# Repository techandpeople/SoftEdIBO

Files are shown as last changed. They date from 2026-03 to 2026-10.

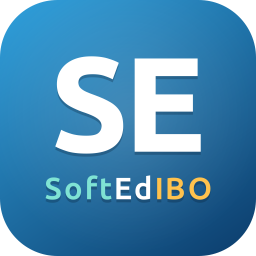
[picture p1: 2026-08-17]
softedibo.png

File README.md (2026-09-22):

# SoftEdIBO

Soft-based robot platform for inclusive, embodied interaction.
Developed at [LASIGE](https://www.lasige.pt/), Faculdade de Ciencias, Universidade de Lisboa.

SoftEdIBO controls soft robots equipped with inflatable air chambers.
Participants interact by touching the robots, which respond through inflation and deflation.
The system supports multiple robot types (Turtle, Tree, Thymio) and activity modes.

> **Running a study?** See [SETUP.md](SETUP.md) for skin/sensor setup, magnet
> polarity, touch calibration, and the gesture-training workflow.

---

## Hardware requirements

| Component | Quantity | Notes |
|---|---|---|
| Seeed XIAO ESP32-S3 (gateway) | 1 | Connected to PC via USB; also runs a WiFi SoftAP (WiFi-OTA) + a UART link to a companion XIAO ESP32-C6 for dongle-free Thymio control |
| Seeed XIAO ESP32-C6 (Thymio RCP) | 0-1 | Optional - impersonates the Thymio RF dongle over 802.15.4 (drive wheels/LEDs/sound, no dongle). See [docs/THYMIO_WIRELESS_CONTROL.md](docs/THYMIO_WIRELESS_CONTROL.md) |
| ESP32-WROOM-32 (`node_direct`) | 1 per direct board | 3 chambers, direct ADC sensors, onboard pumps |
| ESP32-WROOM-32 (`node_multiplexed`) | 1 per multiplexed board | Up to 12 chambers (runtime configurable) |
| DRV3297 motor driver | 1 (`node_direct`) / up to 3 (`node_multiplexed`) | Drives pumps with PWM |
| Air pump | 2 (`node_direct`) / up to 6 (`node_multiplexed`) | Inflate/deflate supply - pumps push directly into the chambers |
| XGZP6847A pressure sensor | 1 per chamber | Analog output (0-3.3 V) |
| Solenoid valves | 2 per chamber | Inflate + deflate via ULN2803A |

Flash the [gateway firmware](firmware/gateway/) to the USB-connected board - one
build, a **Seeed XIAO ESP32-S3** (ESP-IDF), which does everything: ESP-NOW chamber
control + a WiFi SoftAP (for WiFi-OTA) + a UART link to a companion C6 for Thymios.
For each node, choose the matching firmware target:

| Firmware | Path | When to use |
|---|---|---|
| `node_actuator` env `direct` / `direct_debug` | [firmware/node_actuator/](firmware/node_actuator/) | Direct board (fixed 3 chambers) |
| `node_actuator` env `multiplexed` / `multiplexed_debug` | [firmware/node_actuator/](firmware/node_actuator/) | Multiplexed board (default 12 chambers, runtime configurable) |
| `node_magnet_sensor` | [firmware/node_magnet_sensor/](firmware/node_magnet_sensor/) | 4x MLX90393 magnetic touch board (`node_magnet_sensor` protocol) |

---

## Architecture

```
PC --USB--> Gateway (XIAO ESP32-S3) --ESP-NOW--> node_direct      (3 chambers, direct GPIO valves + own pumps)
                                    |        +-> node_multiplexed (up to 12 chambers)
                                    +--UART--> C6 --802.15.4--> Thymio  (dongle-free wheels/LEDs/sound; optional)
```

**Software layers:**

```
SessionPanel
  +-- Activity (declarative behaviours run by ScriptedActivity)
        +-- Robot (Turtle / Tree / Thymio / Simulated)
              +-- Node(s)  (ESP32, identified by MAC + node_type + max_slots)
              +-- Skin(s)  (logical grouping of 1-3 chambers from one node of this robot)
                    +-- AirChamber  (local index 0-2, pressure 0-100 %)
```

- **Node** is a physical ESP32. Its `node_type` (`node_direct` or `node_multiplexed`) determines which firmware to flash.
- **Skin** groups 1-3 chambers, all on the same node (a skin never spans MACs). Activities address chambers by local skin index (0, 1, 2) - no knowledge of node topology required.
- **Pressure** is expressed as **0-100 %** of the maximum pressure configured on each node.
- **Per-chamber max pressure** is set in `settings.yaml` and enforced both in the app and on the ESP32 (hardware safety - survives app crashes).
- **Pressure sensing** uses the XGZP6847A datasheet transfer function (see [pressure.h](firmware/common/pressure.h)).

**Touch sensing (optional).** A skin may reference a `node_magnet_sensor` (4-sensor magnet sensor/touch board) via its `touch:` block - see [firmware/PROTOCOL.md](firmware/PROTOCOL.md). The activity-time view (`SkinGridView`) overlays a pulsing yellow outline on the active sensor cells so the operator sees where each touch lands relative to the chamber regions.

**Skin geometry by type.** Each skin sets a `skin_type` (e.g. `turtle_square`, `tree_round`, `thymio`) whose **shape and sensor coordinates** are hardcoded in [`src/hardware/skin_geometry.py`](src/hardware/skin_geometry.py). The skin dialog offers only the current robot's types and draws the real outline/aspect (square, rectangle, round, triangle, Thymio "D") - editor and activity view share the masks in [`src/gui/skin_shapes.py`](src/gui/skin_shapes.py). The legacy paint-grid editor still applies to skins without a `skin_type`.

**Sensor stream recording + touch-gesture ML.** A session can record every sensor message to `data/recordings/<id>.jsonl` (toggle in the setup dialog - no video). Those recordings, plus gestures tagged live in the observer panel, feed a **per-`skin_type`, coordinate-free** touch-gesture classifier (tap / press / compressions - `src/ml/gesture_taxonomy.py`). `scikit-learn` is the optional `ml` extra; the classifier is inert without a trained model. See [docs/TOUCH_ML.md](docs/TOUCH_ML.md).

**Activities are declarative behaviours.** No activities are hard-coded: every activity is a behaviour spec authored in the block editor (**Tools -> Activity Editor...**), stored in the DB (or imported from JSON examples in `config/examples/behaviours/`) and interpreted at session time by `ScriptedActivity`. See [docs/ACTIVITIES.md](docs/ACTIVITIES.md).

---

## Installation

### Linux (x86-64)

```bash
curl -fsSL https://raw.githubusercontent.com/techandpeople/SoftEdIBO/master/install.sh | bash
```

This will download the latest release, install it to `~/.local/opt/SoftEdIBO/`, create a `softedibo` command in `~/.local/bin/`, and add a desktop entry to the application menu.

**Nightly build** (latest commit on `master`):

```bash
curl -fsSL https://raw.githubusercontent.com/techandpeople/SoftEdIBO/master/install.sh | bash -s -- --nightly
```

**Uninstall:**

```bash
softedibo --uninstall
```

> **First time with USB?** After installing, run:
> ```bash
> sudo usermod -aG dialout $USER
> ```
> Then log out and back in. The installer does this automatically if needed.

---

### Windows (x64)

1. Download **`SoftEdIBO-windows-x64.zip`** from the [latest release](https://github.com/techandpeople/SoftEdIBO/releases/latest)
2. Extract and run **`SoftEdIBO.exe`**

> **USB driver:** install the [CH340](https://www.wch-ic.com/downloads/CH341SER_EXE.html) or [CP210x](https://www.silabs.com/developers/usb-to-uart-bridge-vcp-drivers) driver if your device is not detected.

---

## Usage

On first launch, a setup wizard guides you through flashing the firmware to the ESP32 nodes.

### Configuration (`settings.yaml`)

The app reads and writes the **user copy** of the settings file:
`~/.local/share/SoftEdIBO/config/settings.yaml` on Linux,
`%APPDATA%\SoftEdIBO\config\settings.yaml` on Windows. On first run it is copied
from the bundled default, the repo's [config/settings.yaml](config/settings.yaml);
later edits to the repo file do not reach an existing user copy.

Robots are configured per type (`turtles:` / `trees:` / `thymios:`), each with its own `nodes:` (ESP32s by MAC) and `skins:` on top. A skin lists its chambers - each a `{mac, slot}` pair on a single node - with optional per-chamber `max_pressure` / `min_pressure` safety limits in kPa. It is all editable from the GUI (Robots panel); the commented examples in [config/settings.yaml](config/settings.yaml) show the full shape (skin types, touch blocks, Thymio entries).

```yaml
robots:
  turtles:
    - id: turtle_1
      nodes:
        - mac: "AA:BB:CC:DD:EE:01"
          node_type: "node_multiplexed"
          max_slots: 12
      skins:
        - skin_id: shell_top
          name: Shell Top
          skin_type: turtle_square
          chambers:
            - {mac: "AA:BB:CC:DD:EE:01", slot: 0, max_pressure: 8.0}
            - {mac: "AA:BB:CC:DD:EE:01", slot: 1, max_pressure: 6.0}
  trees: []
  thymios: []
```

- Multiple skins can share the same node MAC; each skin groups up to 3 of that node's slots.
- `max_pressure` is sent to the ESP32 node on startup as kPa. The gateway forwards it unchanged; the node enforces it independently - even if the app crashes, chambers will not exceed their configured limit.
- If `max_pressure` is omitted, chambers default to 8.0 kPa.

---

## Development

### Python application

```bash
# Qt platform libs (Debian/Ubuntu). Without libxcb-cursor0 the app aborts with
# "Could not load the Qt platform plugin xcb" - the app forces xcb (see run.py).
sudo apt-get install -y libgl1 libegl1 libglib2.0-0 libdbus-1-3 \
  libxcb1 libxcb-cursor0 libxcb-icccm4 libxcb-image0 libxcb-keysyms1 \
  libxcb-randr0 libxcb-render-util0 libxcb-shape0 libxcb-xinerama0 \
  libxcb-xkb1 libxkbcommon-x11-0 libfontconfig1

git clone https://github.com/techandpeople/SoftEdIBO.git
cd SoftEdIBO
python -m venv .venv && source .venv/bin/activate
pip install -r requirements.txt
./scripts/compile_ui.sh     # generates src/gui/ui_*.py - not in git
python scripts/run.py
```

Or with the Makefile: `make install && make run` (`make` alone lists every
target - tests, type check, firmware build/flash/monitor, PyInstaller bundle).
`make run` recompiles only the changed `.ui` files on its own.

Requires Python 3.12+. Re-run `./scripts/compile_ui.sh` after editing any
`src/gui/ui/*.ui` file, or the app fails with
`ModuleNotFoundError: No module named 'src.gui.ui_...'`.

**Debug mode** - shows all log levels on the console (DEBUG+):

```bash
python scripts/run.py --debug
```

Without `--debug`, only warnings and errors are shown on the console. All log
levels are always written to `softedibo.log` in the per-user state directory
(`~/.local/state/SoftEdIBO/` on Linux, `%LOCALAPPDATA%\SoftEdIBO\` on Windows;
rotating, 2 MB x 3 backups).

### Firmware

```bash
# Gateway - one build, Seeed XIAO ESP32-S3 (ESP-IDF)
cd firmware/gateway && pio run -e seeed_xiao_esp32s3 --target upload

# Actuator nodes (one project, env per variant)
cd firmware/node_actuator && pio run -e direct      --target upload
cd firmware/node_actuator && pio run -e multiplexed --target upload

# Sensor node (4x MLX90393 touch board)
cd firmware/node_magnet_sensor && pio run -e release --target upload

# Thymio radio co-processor (optional) - Seeed XIAO ESP32-C6
cd firmware/thymio_rcp && pio run -e rcp_c6 --target upload
```

Prebuilt binaries for all of the above are produced by `scripts/build-firmware.sh`.

Requires [PlatformIO](https://platformio.org/).

> **Updating nodes later:** once a node has been cable-flashed once with the
> current partition table, you can reflash it wirelessly via **Tools -> Update
> Nodes (OTA)...** in the app - it streams the bundled firmware to the node over
> ESP-NOW through the connected gateway (no cable, no WiFi). See
> [firmware/gateway/README.md](firmware/gateway/README.md#ota-firmware-update-over-esp-now).

CI builds **every** firmware variant on each run (release + debug, RGB + RGBW)
and ships them all - bundled in the app and in `firmware.zip` - for both the
nightly pre-release (push to `master`) and stable releases (tag `v*`). The debug
build is picked at flash time with the **Debug build** checkbox in the setup
wizard / **Tools -> Update Nodes (OTA)...**.

### Debug builds

| Layer | Production | Development |
|---|---|---|
| **Python app** | `run.py` - warnings only on console | `run.py --debug` - all levels on console |
| **Node firmware** | `release` env - no Serial, no debug overhead | `debug` env - Serial logs, tx counters, `{"cmd":"debug"}` |
| **Gateway firmware** | Single build, no debug overhead | Same (transparent bridge, nothing to gate) |

### Key source paths

| Path | Description |
|---|---|
| `src/hardware/skin.py` | Skin model - groups 1-3 AirChambers on one ESP32 node; `skin_type` + `geometry` |
| `src/hardware/skin_geometry.py` | Hardcoded skin-geometry registry (shape + sensor coords) keyed by `skin_type` |
| `src/hardware/air_chamber.py` | AirChamber model - pressure 0-100 %, configurable max |
| `src/hardware/esp32_controller.py` | Real hardware controller (via the SoftEdIBO gateway) |
| `src/hardware/simulated_controller.py` | Mock controller for simulation mode |
| `src/hardware/touch_profiles.py` | Touch-sensor technology seam (magnet today, capacitive skeleton) - see [docs/TOUCH_SENSORS.md](docs/TOUCH_SENSORS.md) |
| `src/data/stream_recorder.py` | Per-session JSONL recorder of all gateway sensor messages |
| `src/data/export.py` | Session CSV export with robot/participant attribution |
| `src/ml/` | Touch-gesture pipeline (segmenter, features, classifier) - see [docs/TOUCH_ML.md](docs/TOUCH_ML.md) |
| `src/gui/skin_shapes.py` | Shared skin-outline masks (round/triangle/thymio) + aspect ratio |
| `src/robots/` | TurtleRobot, TreeRobot, ThymioRobot, SimulatedRobot |
| `src/activities/` | Activity registry + declarative behaviour engine (`ScriptedActivity`, verb catalogue) |
| `src/gui/monitor/` | Live pressure monitor widgets |
| `scripts/label_touches.py` / `scripts/train_touch_model.py` | Offline touch-gesture labelling + training (`.[ml]` extra) |
| `src/log.py` | Centralized logging setup (console + rotating file) |
| `config/settings.yaml` | Default robot and hardware configuration (copied to the user data dir on first run) |
| `firmware/gateway/` | Gateway firmware (ESP-IDF, Seeed XIAO ESP32-S3) |
| `firmware/thymio_rcp/` | Thymio radio co-processor (XIAO ESP32-C6) - dongle-free 802.15.4 control; see [docs/THYMIO_WIRELESS_CONTROL.md](docs/THYMIO_WIRELESS_CONTROL.md) |
| `firmware/common/` | Shared firmware headers (`se_espnow.h`, units/pressure/dbg/cmd_queue) |
| `firmware/node_actuator/` | Actuator nodes - `direct` + `multiplexed` variants (build-flag envs) |
| `firmware/node_magnet_sensor/` | Sensor node - 4x MLX90393 touch board (`node_magnet_sensor` protocol) |
| `firmware/node_actuator/src/direct/pins.h` | node_direct pin definitions |
| `firmware/node_actuator/src/multiplexed/pins.h` | node_multiplexed pin definitions |

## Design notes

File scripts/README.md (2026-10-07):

# `scripts/`

Developer/operator utilities for SoftEdIBO. Run them from the repo root with the project
venv active (they add the repo to `sys.path` themselves).

## Thymio wireless - control a Thymio over 802.15.4 (no dongle) 

Full protocol + reproduction notes: **[docs/THYMIO_WIRELESS_CONTROL.md](../docs/THYMIO_WIRELESS_CONTROL.md)**
(see the "* ACHIEVED: dongle-free control" section). Quick map:

| script | what it does |
|---|---|
| **`thymio_link.py`** | **the reliable dongle-free drive.** Turns on the C6's firmware `thymio_link` (the C6 polls the Thymio at 10 Hz on its own to hold the link hot) then sends instant `--left/--right/--stop/--led`, **`--sound ID`** (system sound 0-7) / **`--tone HZ DUR`**, or a `--repl` jog (`f/b/l/r/s`, `snd`, `tone`). **Several Thymios on one C6:** `--index` (0..3) + `--addr <hex>` per robot. No dongle at all; runs the leak-fixed `rcp_c6` (prefer a C6 with a proper U.FL antenna - the chip-antenna variant is flaky at range). |
| `thymio_move.py` | one-shot drive - only lands if the link is **already hot** (dongle driving, or a `thymio_link` running); otherwise the Thymio isn't listening. |
| `thymio_tx.py` | send a raw 802.15.4 frame hex (low-level replay/forge) via the C6's `tx` |
| `thymio_sniff_capture.py` | raw `esp_ieee802154` promiscuous sniffer via the C6 - `--scan` finds the channel, `--debug` prints frames live, `--ch N` locks one. (The **raw C6** sniffer sees the Thymio; the Sonoff/OpenThread one filters it out.) |
| `thymio_jog.py` | drive a Thymio via the **RF dongle** (thymiodirect) - the working-today path, and a traffic source to sniff |
| `thymio_signal_test.py` | measure a gateway's RF link to a Thymio (reply rate + RSSI via the C6's active discovery) - run once per gateway/antenna and compare |
| `thymio_sniff_emit.py` | independent-sniffer test with a SECOND gateway: counts the Thymio's on-air sensor-emit frames to tell a dying C6 receiver from a de-associating Thymio RF module |
| `thymio_emit_test.py` | USB isolation test: loads the C6's sensor-push Aseba bytecode over the Thymio's micro-USB cable and counts emitted events for 30 s |
| `thymio_impact_bench.py` | USB bench for the on-board impact-detection Aseba program (hardware tap + acc peak-hold); dumps the bytecode words to bake into the C6 firmware |

**Sound:** `--sound 2` plays a built-in system sound (0-7, -1 stops); `--tone 700 30` plays a
700 Hz tone for 30/60 s. The C6 loads a tiny Aseba program (SET_BYTECODE + RUN) that calls the
`sound.*` native functions - motors keep their targets, so a driving robot beeps without
stopping. In the app / Python: `robot.play_sound(system=2)` or
`robot.play_sound(freq=700, duration_ms=500)`.

**Several Thymios:** one C6 drives up to 4, each a **slot** (`--index`) addressed by its
802.15.4 short **`--addr`** (hex, e.g. `6a25`). Discover the addresses in-app (Robot Config ->
Thymio -> **Discover...**: a dongle-free active scan - the C6 broadcasts LIST_NODES and every
powered robot on the network answers; power them on one at a time to map address -> robot,
listed in first-seen order), read a brand-new robot's address over its USB cable (Robot
Config -> Thymio -> **From cable...** - wireless Discover only sees robots already paired to
this network), or use `thymio_sniff_capture.py`. In the app, set each Thymio's
**Address (C6)** so `wireless_via: gateway` robots get distinct slots.

### 60-second quickstart (dongle-free)
```bash
# 1) flash a XIAO ESP32-C6 with the RCP (sniff + tx + sound; prefer the U.FL-antenna C6):
pio run -d firmware/thymio_rcp -e rcp_c6 -t upload
ls /dev/serial/by-id/                     # note the C6 port (Espressif)

# 2) find the Thymio's 802.15.4 channel (drive it in one terminal, sniff in another):
python scripts/thymio_jog.py --drive 100 -100 --secs 180        # robot spins (via dongle)
python scripts/thymio_sniff_capture.py --no-drive --debug --gateway /dev/ttyACM<C6>
#   look for a frame whose data contains 8144 (PAN 0x4481) -> its "ch" is the channel

# 3) drive it dongle-free, no dongle at all (was channel 25):
python scripts/thymio_link.py --ch 25 --gateway /dev/ttyACM<C6> --repl        # live jog: f/b/l/r/s
python scripts/thymio_link.py --ch 25 --gateway /dev/ttyACM<C6> --left 150 --right 150
python scripts/thymio_link.py --ch 25 --gateway /dev/ttyACM<C6> --stop
```
Prefer the stable `/dev/serial/by-id/...` path for `--gateway` - the `ttyACM*` numbers shift
when you plug/unplug other devices. If you re-pair the Thymio to a new network, only the
**channel** usually changes (set it with `--ch`); the PAN/addresses are read off the air and
rarely move.

## Other utilities
| script | purpose |
|---|---|
| `run.py` | launch the GUI app (sets the Qt env - `xcb` platform, shared GL contexts, WebEngine flags - then starts the app) |
| `build-firmware.sh` | build the bundled node/gateway firmware bins for OTA |
| `ota_c6_wifi.py` | one-command WiFi-OTA of the gateway's C6 (Thymio RCP) |
| `ota_nodes.py` | OTA-flash every online configured node through the gateway (`make flash-nodes`); `--led rgb|rgbw` forces the LED variant, `--dry-run` only lists the plan |
| `emergency-flash.sh` | cable-flash a bricked node through a second ESP as a serial bridge |
| `compile_ui.sh` | compile Qt Designer `.ui` files to `ui_*.py` |
| `fetch_blockly.sh` | vendor Blockly for the Activity Editor |
| `label_touches.py`, `train_touch_model.py` | touch-sensor dataset labelling + ML training |
| `touch_position_bench.py` | touch-position feasibility bench (Phase 0): guided grid/pattern capture on a skin + analysis report; CLI mirror of Tools -> Touch Position Bench... (docs/TOUCH_POSITION_ML_PLAN.md) |
| `draw_icon.py` | draw `softedibo.png` (the app artwork) from vector code |
| `make_icon.py` | regenerate the multi-size Windows `softedibo.ico` from `softedibo.png` |

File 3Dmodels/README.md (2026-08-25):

# 3D models

Layout rule: `<area>/<object>/<FORMAT>/<Part>.<ext>`

- `<FORMAT>`  STL (print-ready), STEP (exchange), F3D (Fusion 360 source), DXF (2D profiles / templates to sketch new models from)
- `<area>`    Enclosures | SkinMolds | Gateway
- `<object>`  the robot or part group (Thymio, Tree, Turtle, CommonBase, OrganBoxes, Shared)

A `.f3d` is a Fusion design and usually holds SEVERAL bodies, so one source
exports several parts. Exports are named by part, not by source:

    Enclosures/Thymio/F3D/ThymioSkinAdapter.f3d
      -> STL/ThymioSkinAdapter.stl, ThymioSkinHolder.stl, ThymioSkinCover.stl, ThymioLEDGuard.stl
      -> STEP/ (same names)

Files with a `-alt` / `-FIXME` suffix are unresolved variants.

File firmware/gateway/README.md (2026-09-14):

# SoftEdIBO Gateway Firmware

Bridges USB/serial (PC) <-> ESP-NOW (nodes). The ESP-NOW / MAC / radio plumbing
is shared with the node firmwares via `firmware/common/se_espnow.h`.

## One build - Seeed XIAO ESP32-S3

The gateway is a **Seeed XIAO ESP32-S3** (Xtensa dual-core, native USB-Serial/JTAG),
ESP-IDF, `src/main.cpp` (cJSON). One build (`seeed_xiao_esp32s3` -> `firmware-s3.bin`)
does everything: ESP-NOW chamber control **+** a SoftAP for the Thymios / WiFi-OTA
(`-DGATEWAY_AP`) **+** a UART link to a companion XIAO ESP32-C6 that speaks 802.15.4 to
Thymio robots (`-DGATEWAY_THYMIO`, see `docs/THYMIO_WIRELESS_CONTROL.md`). The dual-core
headroom keeps the ESP-NOW bridge responsive while WiFi clients are associated (the bridge
runs on the second core); PSRAM buffers the WiFi-OTA image. Baud rate 115200.

## Build & Flash

```bash
cd firmware/gateway
pio run -e seeed_xiao_esp32s3 --target upload
```

### WiFi access point (`-DGATEWAY_AP`, always on)

The gateway runs a **SoftAP** so WiFi clients (e.g. Thymio robots) can associate **while
ESP-NOW keeps running** - the two share one 2.4 GHz radio, so the AP and the nodes are on
the **same channel** (default 1). Defaults: SSID `SoftEdIBO`, password `softedibo`,
channel 1, up to 8 clients - override at build time:

```bash
pio run -e seeed_xiao_esp32s3 \
  -a '-DGATEWAY_AP_SSID="MyNet" -DGATEWAY_AP_PASS="secret12" -DGATEWAY_AP_CHANNEL=6'
```

The gateway announces itself with an `"ap"` field on boot:
`{"status":"gateway_ready","mac":"...","ap":"SoftEdIBO"}`.

The SSID/password can be changed at **runtime** (no reflash) via two
gateway-local commands - JSON lines **without** a `"target"`, so the gateway
handles them itself instead of forwarding over ESP-NOW. New values persist in
NVS. The desktop app exposes this in **Tools -> Update Nodes (OTA)...** (the AP
network field + **Save AP**, auto-filled from the gateway).

```jsonc
// PC => gateway
{"cmd":"get_ap"}
{"cmd":"set_ap","ssid":"MyNet","pass":"secret12","channel":6}   // pass/channel optional (keep current)
// gateway => PC
{"type":"ap_config","ssid":"SoftEdIBO","channel":1,"secured":true}
{"type":"ap_set","ok":true,"ssid":"MyNet"}
{"type":"ap_set","ok":false,"reason":"bad_password"}   // or "empty_ssid"
{"type":"error","reason":"ap_not_supported"}           // non-AP build
```

This SoftAP also powers the **fast WiFi firmware update** (S3 only - it buffers
the image in PSRAM). In the desktop app's **Tools -> Update Nodes (OTA)...** pick the
*WiFi* transport: the PC streams the image to the gateway over the **USB cable**
(`ota_store_*` gateway-local commands), the gateway buffers it in PSRAM and serves
it over HTTP (`http://<ap-ip>/fw`, with an `x-MD5` header), and the node joins the
AP to download it in seconds. The **PC never joins the WiFi** - it stays on the
cable. The node side is `firmware/common/se_ota.h` (the `ota_wifi` command); the
gateway proxy is in `src/main.cpp`.

```jsonc
// PC => gateway (no "target"): stage the image, then trigger the node
{"cmd":"ota_store_begin","size":806976,"md5":"..."}
{"type":"ota_store_ready"}                       // or {"type":"ota_store_error","reason":"no_psram"}
{"cmd":"ota_store_data","data":"<base64>"}        // xN
{"type":"ota_store_ack","len":8192}               // cumulative, every 4 KB stored - the PC
                                                  // windows its sends on these (USB flow control)
{"cmd":"ota_store_end"}
{"type":"ota_stored","ok":true,"size":806976,"url":"http://192.168.4.1/fw"}
// staging errors ("reason"): bad_size, no_psram, httpd_failed, not_storing,
// size_mismatch (+got/want), md5_mismatch; ap_not_supported on a non-AP build
```

The gateway MD5-checks the staged image before serving it, and injects its own
AP `ssid`/`pass` into any forwarded `ota_wifi` command that doesn't carry one -
so the PC never needs to know the AP credentials and a renamed AP can't break
OTA.

Requires [PlatformIO](https://platformio.org/). The XIAO ESP32-S3 needs ESP-IDF 5.x - the
official `espressif32` 6.x ships Arduino core 2.x, so the env pins the **pioarduino**
platform fork (verified: IDF 5.5.4). Native ESP-IDF also works (shared `CMakeLists.txt`):

```bash
cd firmware/gateway
idf.py set-target esp32s3 && idf.py build flash
```

## Serial Protocol (newline-terminated JSON)

**PC => Gateway** - every command must include a `"target"` MAC:
```json
{"target":"AA:BB:CC:DD:EE:01","cmd":"set_max_pressure","chamber":0,"value":80}
{"target":"AA:BB:CC:DD:EE:01","cmd":"inflate","chamber":0,"delta":20}
{"target":"AA:BB:CC:DD:EE:01","cmd":"deflate","chamber":1,"delta":15}
{"target":"AA:BB:CC:DD:EE:01","cmd":"set_pressure","chamber":2,"value":75}
{"target":"AA:BB:CC:DD:EE:01","cmd":"hold","chamber":0}
{"target":"FF:FF:FF:FF:FF:FF","cmd":"ping"}
{"target":"AA:BB:CC:DD:EE:01","cmd":"debug"}
```

The gateway strips `"target"` before forwarding so nodes receive only the command fields.
Two `"target"` values are special:

- **no `"target"`** - gateway-local command (`get_ap`, `set_ap`, `ota_store_*` above);
- **`"target":"thymio"`** - forwarded over UART to the companion C6 radio
  co-processor (`thymio_*` commands, see `docs/THYMIO_WIRELESS_CONTROL.md`);
  the C6's replies come back tagged `{"source":"thymio",...}`.

**Gateway => PC** - every message from a node gets a `"source"` MAC added:
```json
{"source":"AA:BB:CC:DD:EE:01","type":"status","kpa":[6.0,0.2,0.0],"st":[0,0,0],"vi":[0,0,0],"vd":[0,0,0]}
{"source":"AA:BB:CC:DD:EE:01","type":"pong","rgbw":true,"kpa_min":0}
{"source":"AA:BB:CC:DD:EE:01","type":"debug","ch":[...],"tx_ok":1520,"tx_fail":3,"drop":0,"up":342}
{"status":"gateway_ready","mac":"AA:BB:CC:DD:EE:00","ap":"SoftEdIBO"}
```

A PC line that fails to parse (usually USB byte loss) is reported back as
`{"type":"error","reason":"bad_cmd_json","len":N,"raw":"..."}` instead of being
silently dropped, so a swallowed command (e.g. a missed `stop`) is visible.

Actuator `status` is ONE batched frame per node: parallel per-chamber arrays
`kpa[]` (kPa), `st[]` (0 idle, 1 inflating, 2 deflating) and `vi[]`/`vd[]`
(actual inflate/deflate valve outputs). It carries no `pressure` % - the PC
recomputes it from `kpa` against the configured range. Commands that take a
`"value"` in % (`set_pressure`) mean 0-100 % of the chamber's configured
[min, max] range; `set_max_pressure`/`set_min_pressure` take kPa.
See [`../PROTOCOL.md`](../PROTOCOL.md) for the full command/reply reference.
The `"debug"` response is only available from nodes flashed with the debug firmware.

Maximum line length: **512 bytes** (`SERIAL_BUF_LEN` constant). It was raised
from 256 for OTA: an `ota_data` line carries a base64 chunk *plus* the `"target"`
MAC, which overflows 256.

## OTA firmware update (over ESP-NOW)

Nodes can be reflashed wirelessly through the gateway - the PC streams the image
as ordinary JSON commands, the gateway relays them unchanged, and the node
writes flash via `firmware/common/se_ota.h`. Driven PC-side by
`src/hardware/node_ota_updater.py`; the gateway itself needs no OTA-specific code
(only the larger line buffer above).

```jsonc
// PC => node
{"target":"AA:..","cmd":"ota_begin","size":768929,"md5":"<hex>","chunk":96}
{"target":"AA:..","cmd":"ota_data","seq":0,"data":"<base64 of 96 bytes>"}
{"target":"AA:..","cmd":"ota_end"}
// node => PC
{"source":"AA:..","type":"ota_ready"}
{"source":"AA:..","type":"ota_ack","seq":0}
{"source":"AA:..","type":"ota_done"}          // node then reboots
{"source":"AA:..","type":"ota_error","reason":"verify_failed"}
```

Chunk = 96 raw bytes (-> 128 base64 chars; the gateway->node relay drops
payloads over ~190 bytes, so chunks stay well under that - see
`node_ota_updater.CHUNK_SIZE`). The node tolerates a sliding window (re-ACKs
duplicates, drops out-of-order future chunks); the PC retransmits on a
per-sequence timeout, verifies the image with the MD5 from `ota_begin`, and
only treats the update as done when the freshly-booted new firmware broadcasts
`ota_done`. Nodes need an OTA partition table (`default.csv`); see each node's
`platformio.ini`.

## Behaviour

- On boot sends `{"status":"gateway_ready","mac":"..."}` to serial.
- Reads serial line-by-line using a **fixed stack buffer** (no heap allocation).
- Forwards every JSON command from serial to the `target` MAC via ESP-NOW,
  stripping the `"target"` field before forwarding.
- Forwards every ESP-NOW message received from nodes to serial, adding a
  `"source"` field with the sender MAC.
- Broadcast address `FF:FF:FF:FF:FF:FF` is pre-registered as peer for scan/ping.
- Unknown sender MACs are dynamically added as peers on first send.
- PC->node forwards are **paced** (`se::sendPaced` waits for the previous
  frame's TX-done before sending the next), so a burst of back-to-back
  commands (e.g. a batch inflate) can't overrun the radio's tiny TX queue and
  silently drop frames.
- Still **fire-and-forget** - no retransmit. ESP-NOW provides link-layer
  ACKs automatically; the app can resend if it doesn't see a pressure change.

## Performance notes

- The serial read loop uses a **fixed char buffer** - zero heap allocation per
  received line.
- ESP-NOW receives run in the WiFi task: the callback only copies the payload
  into a **FreeRTOS queue**; a dedicated task serialises (cJSON) and writes to
  USB, so the radio stack never blocks on serial I/O.
- JSON is handled with **cJSON** (bundled in ESP-IDF) - no external dependency.

## Important caveats

- ESP-NOW and WiFi share the same radio. The gateway runs in `WIFI_STA` mode
  **without** connecting to an AP (channel 1 by default). Nodes must be on the
  same WiFi channel. The `-DGATEWAY_AP` build adds a SoftAP (`WIFI_APSTA`) on
  that same channel - the single radio is time-shared between AP traffic and
  ESP-NOW, so heavy client traffic competes for airtime with the nodes.
- Maximum ESP-NOW payload: **250 bytes**. Keep JSON commands short.
- The `esp_now_peer_info_t.channel = 0` means "use current channel". If you
  change the WiFi channel, all peers must be re-added.

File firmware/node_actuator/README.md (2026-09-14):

# node_actuator Firmware

Pneumatic actuator boards. One PlatformIO project hosts **both** board variants,
selected at build time via `build_src_filter`:

| Variant | Sources | `node_type` | Description |
|---|---|---|---|
| `direct` | `src/direct/` | `node_direct` | 3 chambers, GPIO valves via ULN2803A, onboard pumps via DRV3297; optional folded-in MLX90393 magnet/touch module (auto-detected) |
| `multiplexed` | `src/multiplexed/` | `node_multiplexed` | Up to 12 chambers, muxed valves/sensors (2x PCA9685 + 74HC4067), shared pump banks (no reservoir tanks in the current build), 3 LED rings (`NUM_RINGS`) |

Each variant has a release env, a `*_debug` env (adds Serial logs + the
`debug` command, `-DDEBUG_BUILD`), and `*_rgbw` / `*_rgbw_debug` envs for
SK6812 RGBW rings (`-DLED_RGBW` - the node self-reports `rgbw` in ready/pong
so the OTA picker selects the right bin).

## Build & flash

```bash
cd firmware/node_actuator
pio run -e direct             --target upload   # node_direct, release
pio run -e direct_debug       --target upload   # node_direct, debug
pio run -e multiplexed        --target upload   # node_multiplexed, release
pio run -e multiplexed_debug  --target upload   # node_multiplexed, debug
pio run -e direct_rgbw        --target upload   # RGBW-ring variants (also
pio run -e multiplexed_rgbw   --target upload   #  *_rgbw_debug)
```

`pio run` (no `-e`) builds all eight.

## Shared code

ESP-NOW/MAC/radio plumbing and the common helpers come from `firmware/common`
(added to the include path in `platformio.ini`):

- `se_espnow.h` - ESP-NOW init, peers, paced send, gateway-MAC tracking (also
  used by the gateway and node_magnet_sensor).
- `coupled_fill.h` - shared coupled-line fill supervisor (the engine both
  boards drive their fills through) so the two boards can't drift.
- `se_ota.h` - OTA receiver (ESP-NOW chunk stream + WiFi pull).
- `se_magnet.h` - MLX90393 magnet/touch module (direct board folds it in).
- `hold_duty.h` - leak-compensating regulated hold (`hold_duty` command).
- `units.h`, `pressure.h`, `pump_duty.h`, `dbg.h`, `cmd_queue.h` - shared by both variants.

Variant-specific modules (`pins.h`, `chambers.h`, `commands.h`, `leds.h`,
`organ.h`, `magnet.h`, `mux.h`, `pca_valves.h`, `pumps.h`, `config.h`) live
under each `src/<variant>/` folder.

See [../PROTOCOL.md](../PROTOCOL.md) for the ESP-NOW command/status protocol.

## Fill / deflate safety

`inflate`/`deflate` take `{chamber, delta, ms, duty}` and route through the
shared coupled-fill engine (`coupled_fill.h`): co-active same-direction
chambers open together, each closes progressively at its own target, then one
settle + isolated verify. `ms>0` is that chamber's valve-open time budget -
the closing authority for a target the gauge can't see (a deflate below the
sensor floor, timed from the PC's calibrated deflate curve).

Safety is **time-based** (the gauge is unreliable and blind below its floor):
per-chamber cumulative open cap 5 s (`chamber_max_ms`, overridden per request
by `ms`), per-round cap 6 s (direct) / 8 s (multiplexed), whole-sequence cap
25 s (direct) / 45 s (multiplexed), a 10 s actuation
watchdog (`ACTUATION_TIMEOUT_MS`), and a 5 s dead-man on the manual/bench
paths. `HARD_MAX/MIN_KPA` (+/-100) is effectively uncapped - a single-sample
inflate cut kept only for a sane gauge. Full model:
[../../docs/PRESSURE_AND_FILL_SAFETY.md](../../docs/PRESSURE_AND_FILL_SAFETY.md).

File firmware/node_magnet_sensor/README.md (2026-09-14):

# node_magnet_sensor Firmware

Touch-sensing board: 4x MLX90393 magnetometers (+1 optional 5th on a second I2C
bus). A magnet sits above each sensor inside the silicone; pressing the skin
moves the magnet and changes the measured field. The board streams the
**node_magnet_sensor protocol** over ESP-NOW so it plugs straight into the SoftEdIBO PC
(`QuadrantDetector` / touch tracking).

Adapted from the thesis MLX90393 live-stream firmware. The offline **calibration
protocol (CSV) was intentionally dropped**: the SoftEdIBO runtime detects touch
with thresholds on the raw uT magnitudes (`QuadrantDetector`), not a calibrated
model. The only "calibration" the runtime needs is the per-sensor baseline,
which this firmware computes automatically (see below).

## Hardware

- **Board:** ESP32-WROOM-32 (esp32dev) - kept on its own ESP for now.
- **Primary I2C** (sensors S0..S3): SDA = IO21, SCL = IO22, addrs `0x18 0x19 0x1A 0x1B`.
- **Secondary I2C** (optional 5th sensor, S4): SDA = IO16, SCL = IO17, addr `0x1A`.
  It only takes a slot when it actually responds, so it always lands after the
  quadrant sensors.
- MLX90393 config: gain 2x, OSR 2, filter 3 (~=28 Hz with 4 sensors).

Sensor order is significant: **S0->Q1 (top-left), S1->Q2 (top-right),
S2->Q3 (bottom-left), S3->Q4 (bottom-right)** - matches the PC `QuadrantDetector`
(which consumes the first 4 sensors; the optional 5th is appended after them).

## ESP-NOW protocol

**Boot** (broadcast; re-broadcast every 2 s until the gateway is known, so a
late-connecting PC still sees it - and sent even if no sensor responds, so a
board with dead sensors stays visible in scans):
```json
{"status":"node_magnet_sensor_ready","sensors":4,"variant":"mlx90393","fw":"magvec-1"}
```

**Stream** (~28 Hz, to the gateway once it is known):
```json
{"type":"magnet","mag":[uT,...],"act":[active_idx,...]}
```
- `mag` - per-sensor field-change magnitude in uT (`|sample - baseline|`).
- `act` - indices of sensors whose `mag >= act_threshold_ut` (the value the PC
  prefers; firmware default 300 uT until configured).

**3-axis streaming:** the stream message can additionally carry
`"vec":[[dx,dy,dz],...]` - the per-sensor baseline-subtracted field delta in
uT (one decimal for components below 100 uT, whole uT above) - and the boot announce then gains `"vec":1`. `mag`/`act` are
unchanged, so the PC pipeline is unaffected; the direction information enables
vector touch compensation and richer offline analysis (`docs/TOUCH_COUPLING.md`).
Two ways to turn it on: the `[env:vector]` build (`-DMAG_VECTOR`) enables it
from boot (flash `[env:release]` to revert), or
`{"cmd":"configure","stream_vec":true}` toggles it at runtime on any build
(RAM-only - cleared by a reboot; the PC re-sends it when it needs vectors).

**Shared module:** all sensing/streaming logic lives in
`firmware/common/se_magnet.h`, which the direct actuator board
(`node_actuator` `[env:direct*]`) folds in too - one implementation, two
boards. This file only wires the buses, command dispatch and OTA.

**Commands** (PC -> board, via gateway):
```json
{"cmd":"ping"}                                  // -> {"type":"pong"}
{"cmd":"rebaseline"}                            // re-zero all sensors now
{"cmd":"configure","act_threshold_ut":100}      // uT at/above which a sensor is "active"
{"cmd":"configure","adaptive_baseline":true,"baseline_tau_ms":2000}
{"cmd":"configure","osr":2,"filter":3}          // MLX90393 oversampling 0-3 / filter 0-7; re-captures the baseline
```
Legacy `configure` fields (`fullscale_mt`, `act_threshold` as a 0..1 fraction) are
still accepted, converted to `act_threshold_ut = act_threshold x fullscale_mt`.

### Baseline (auto-zero)
Each sensor is auto-zeroed at boot by averaging the first 70 reads. Re-zero at
runtime with `{"cmd":"rebaseline"}` (e.g. after the silicone settles, or if the
board was touched during boot). Streaming pauses until the baseline is ready.

**Adaptive baseline (opt-in).** `{"cmd":"configure","adaptive_baseline":true,
"baseline_tau_ms":2000}` makes the baseline keep tracking slow drift after boot -
e.g. a chamber inflating under the magnet - so it isn't read as a touch. Frozen
per-sensor while that sensor is active (real touches survive); EWMA uses the real
elapsed time, so it's immune to ESP-NOW jitter. Off by default - only enable once
a coupling sweep confirms actuation contamination. See `docs/TOUCH_COUPLING.md`.

## Build & flash
```bash
cd firmware/node_magnet_sensor
pio run -e release --target upload     # default (scalar protocol)
pio run -e vector  --target upload     # + 3-axis "vec" streaming from boot
pio run -e debug   --target upload     # Serial logs (-DDEBUG_BUILD)
```
Uses the shared `firmware/common/se_espnow.h` (added to the include path in
`platformio.ini`), the same ESP-NOW layer as the actuator nodes and the gateway.
The board also accepts the shared `ota_*` commands (`se_ota.h`, ESP-NOW chunk
stream + WiFi pull); the OTA partition table (`default.csv`) is set in
`platformio.ini` - a board on a non-OTA table needs one cable flash first.

---

## Planned / TODO - scale to ~12 sensors via I2C (not yet implemented)

A colleague flagged that **more I2C will be needed to support ~3x the sensors**
(i.e. ~12 instead of the current 4). This runs into a hard limit:

- The **MLX90393 has only 4 I2C addresses** per bus (`0x18-0x1B`, set by its 2
  address pins). The ESP32 has **2 hardware I2C controllers** (`Wire`, `Wire1`),
  so **8 sensors is the ceiling without extra hardware**.
- For ~12 sensors, add an **I2C multiplexer (TCA9548A)**: one bus fans out into
  8 channels, each carrying up to 4 MLX90393. Select the channel, then talk to
  the sensor at its address.

### Gaps to close when implementing
1. **Hardware:** add a TCA9548A on the primary bus (IO21/IO22). Each touch point
   = (mux channel, MLX address).
2. **Firmware:** replace the fixed `PRIMARY_ADDR[4]` + single extra bus
   (`main.cpp`) with a sensor table of `{mux_channel, address}`, select the
   channel before each `readData`, and raise `se::magnet::MAX_SENSORS`
   (`firmware/common/se_magnet.h`, currently 5) to 12. The `mag`/`act` arrays
   already scale with the wired sensor count.
3. **PC side:** `QuadrantDetector` is **hardcoded to exactly 4 sensors**
   (`src/hardware/quadrant_detector.py` - `raise ValueError` if != 4). With 12
   sensors the 4-quadrant model no longer fits; route sensors to chambers via
   each skin's `touch.sensor_grid` / `sensor_to_chamber` map instead (the skin
   editor already supports per-sensor grids). Generalising the detector is OK -
   it was brought in from the thesis and is not yet validated.

The sensor count, layout and addressing should be confirmed with the colleague
before implementing.

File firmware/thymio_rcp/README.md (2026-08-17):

# Thymio RCP (XIAO ESP32-C6)

The **radio co-processor (RCP)** firmware that drives Thymio robots wirelessly
**without the Thymio RF dongle**. Background and the full plan are in
[docs/THYMIO_WIRELESS_CONTROL.md](../../docs/THYMIO_WIRELESS_CONTROL.md).

One build - **`rcp_c6`**, flashed onto a XIAO **ESP32-C6**. It is
**transport-agnostic**: it services *both* its own USB-Serial/JTAG port and the
inter-board UART to the S3 host, and replies on whichever channel a line arrived
on (no host simply means no bytes, so a disconnected USB never stalls it). The
same binary therefore works flashed-solo-on-USB for bench testing *and* wired to
the S3 gateway in production - no rebuild, no mode jumper. The S3 gateway forwards
`{"target":"thymio",...}` lines to it over UART and tags its replies `"source":"thymio"`.

What it does (all over the C6's own 802.15.4 radio - see the docs for the protocol):

- **`thymio_link`** - *be* the dongle: poll the Thymio ~10 Hz to hold its receive
  window open and assert the held motor/LED targets (`thymio_drive` / `thymio_leds` /
  `thymio_sound`), for up to 4 robots addressed by slot (`thymio_set`).
- **sensors** - the same link poll also reads `acc` / `mic` / `ground` and forwards
  them as `{"type":"thymio_sensors",...}` (raw reply frames via `thymio_rx_debug`).
- **`thymio_discover`** - broadcast Aseba `LIST_NODES`; report each replying robot's
  address as `{"type":"thymio_found","addr":"6a25"}`.
- **`sniff_start` / `sniff_ch` / `sniff_stop`** - promiscuous 802.15.4 capture (raw
  frames as `{"type":"frame",...}`), the Phase-1 protocol reverse-engineering.
- **`tx`** - transmit a raw frame hex (replay / forge).
- **`ota_wifi`** - WiFi-OTA self-update from the S3's SoftAP; flashed once over USB,
  every update after comes over the air.
- **`ping`** / bare `PING <n>` - bring-up check: a `{"type":"pong"}` / `PONG <n>`
  proves the C6 received the line *and ran code on it* (a shorted wire would only
  echo `PING` back).

## Wiring (4 wires)

| S3 (host) | <-> | C6 (RCP) |
|---|---|---|
| D6/TX (GPIO43) | -> | D7/RX (GPIO17) |
| D7/RX (GPIO44) | <- | D6/TX (GPIO16) |
| GND | - | GND (common ground, required) |
| 5V (VBUS) | -> | 5V (VBUS) - one USB cable powers both |

Both boards are 3.3 V logic, so the UART connects directly (no level shifter).
Do **not** tie the two `3V3` pads together - power flows 5V -> 5V only.

## Build & flash

```bash
cd firmware/thymio_rcp
pio run -e rcp_c6 -t upload        # first flash over the C6's own USB
pio device monitor                 # 115200 baud
```

After this first USB flash the C6 needs no USB again - updates go over WiFi-OTA
from the S3's SoftAP (Tools -> Update Nodes (OTA)... -> the "C6 (Thymio RCP)" row, or
`scripts/ota_c6_wifi.py`).

## Bench test over USB (no S3, no soldering)

The one build runs standalone on the C6's USB, so you can exercise it before the
inter-board link is soldered. In the monitor (type directly - no `"target"` wrapper):

```
PING 1                  -> PONG 1                            (bring-up echo)
{"cmd":"ping"}          -> {"type":"pong","src":"c6"}
{"cmd":"sniff_start"}   -> {"type":"frame",...}  once a Wireless Thymio is powered nearby
```

A `PONG` proves the C6 received the line *and ran code on it*. A spare C6 on USB
running this same build is also how you sniff or drive a Thymio directly, reading
its replies over its own USB - see the docs.

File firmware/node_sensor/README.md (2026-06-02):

# node_sensor Firmware

Touch-sensing board: 4× MLX90393 magnetometers (+1 optional 5th on a second I2C
bus). A magnet sits above each sensor inside the silicone; pressing the skin
moves the magnet and changes the measured field. The board streams the
**node_imu protocol** over ESP-NOW so it plugs straight into the SoftEdIBO PC
(`QuadrantDetector` / touch tracking).

Adapted from the thesis MLX90393 live-stream firmware. The offline **calibration
protocol (CSV) was intentionally dropped**: the SoftEdIBO runtime detects touch
with thresholds on the normalised values (`QuadrantDetector`), not a calibrated
model. The only "calibration" the runtime needs is the per-sensor baseline,
which this firmware computes automatically (see below).

## Hardware

- **Board:** ESP32-WROOM-32 (esp32dev) — kept on its own ESP for now.
- **Primary I2C** (sensors S0..S3): SDA = IO21, SCL = IO22, addrs `0x18 0x19 0x1A 0x1B`.
- **Secondary I2C** (optional S5): SDA = IO16, SCL = IO17, addr `0x1A`.
- MLX90393 config: gain 2×, OSR 2, filter 3 (≈28 Hz with 4 sensors).

Sensor order is significant: **S0→Q1 (top-left), S1→Q2 (top-right),
S2→Q3 (bottom-left), S3→Q4 (bottom-right)** — matches the PC `QuadrantDetector`
(which consumes the first 4 sensors; the optional 5th is appended after them).

## ESP-NOW protocol

**Boot** (broadcast):
```json
{"status":"node_imu_ready","sensors":4,"variant":"mlx90393"}
```

**Stream** (~28 Hz, to the gateway once it is known):
```json
{"type":"imu","mag":[mT,...],"adj":[0.0-1.0,...],"act":[active_idx,...]}
```
- `mag` — per-sensor field-change magnitude in mT (`|sample − baseline|`).
- `adj` — `mag / fullscale_mt`, clamped 0..1 (the value the PC prefers).
- `act` — indices of sensors whose `adj ≥ act_threshold`.

**Commands** (PC → board, via gateway):
```json
{"cmd":"ping"}                                  // -> {"type":"pong"}
{"cmd":"rebaseline"}                            // re-zero all sensors now
{"cmd":"configure","fullscale_mt":30,"act_threshold":0.2}
```

### Baseline (auto-zero)
Each sensor is auto-zeroed at boot by averaging the first 70 reads. Re-zero at
runtime with `{"cmd":"rebaseline"}` (e.g. after the silicone settles, or if the
board was touched during boot). Streaming pauses until the baseline is ready.

## Build & flash
```bash
cd firmware/node_sensor
pio run --target upload
```
Uses the shared `firmware/common/se_espnow.h` (added to the include path in
`platformio.ini`), the same ESP-NOW layer as the actuator nodes and the gateway.

---

## Planned / TODO — scale to ~12 sensors via I2C (not yet implemented)

A colleague flagged that **more I2C will be needed to support ~3× the sensors**
(i.e. ~12 instead of the current 4). This runs into a hard limit:

- The **MLX90393 has only 4 I2C addresses** per bus (`0x18–0x1B`, set by its 2
  address pins). The ESP32 has **2 hardware I2C controllers** (`Wire`, `Wire1`),
  so **8 sensors is the ceiling without extra hardware**.
- For ~12 sensors, add an **I2C multiplexer (TCA9548A)**: one bus fans out into
  8 channels, each carrying up to 4 MLX90393. Select the channel, then talk to
  the sensor at its address.

### Gaps to close when implementing
1. **Hardware:** add a TCA9548A on the primary bus (IO21/IO22). Each touch point
   = (mux channel, MLX address).
2. **Firmware (this file):** replace the fixed `PRIMARY_ADDR[4]` + single extra
   bus with a sensor table of `{mux_channel, address}`, select the channel
   before each `readData`, and let `streamCount` grow to 12. The `mag`/`adj`/
   `act` arrays already scale with `streamCount`.
3. **PC side:** `QuadrantDetector` is **hardcoded to exactly 4 sensors**
   (`src/hardware/quadrant_detector.py` — `raise ValueError` if ≠ 4). With 12
   sensors the 4-quadrant model no longer fits; route sensors to chambers via
   each skin's `touch.sensor_grid` / `sensor_to_chamber` map instead (the skin
   editor already supports per-sensor grids). Generalising the detector is OK —
   it was brought in from the thesis and is not yet validated.

The sensor count, layout and addressing should be confirmed with the colleague
before implementing.

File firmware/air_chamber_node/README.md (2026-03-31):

# Air Chamber Node Firmware

ESP32-WROOM-32 firmware for nodes that control 3 inflatable air chambers
via solenoid valves and two DRV8833-driven pumps.

## Hardware (per node)

| Component | GPIO |
|---|---|
| Chamber 0 — inflate valve | 22 |
| Chamber 0 — deflate valve | 23 |
| Chamber 1 — inflate valve | 21 |
| Chamber 1 — deflate valve | 13 |
| Chamber 2 — inflate valve | 14 |
| Chamber 2 — deflate valve | 33 |
| Inflate pump — DRV8833 ch A (PWM) | 25 |
| Deflate pump — DRV8833 ch B (PWM) | 26 |
| Pressure sensor ch0 — XGZP6847A (ADC) | 34 |
| Pressure sensor ch1 — XGZP6847A (ADC) | 35 |
| Pressure sensor ch2 — XGZP6847A (ADC) | 32 |

Pin definitions are in [`src/pins.h`](src/pins.h).

Valves: `HIGH` = open, `LOW` = closed.
Pumps: DRV8833 H-bridge, single PWM pin per channel (other pin tied on PCB).

## Build & Flash

Two build environments — **release** (production) and **debug** (development):

```bash
# Production — no Serial output, no debug overhead
pio run -e release --target upload

# Development — Serial logs, tx counters, "debug" command via ESP-NOW
pio run -e debug --target upload
```

The CI pipeline automatically selects the right environment:
- **Nightly** (push to `master`) → `debug` build
- **Stable release** (tag `v*`) → `release` build

## Pressure sensing

Pressure is read from XGZP6847A sensors using the datasheet transfer function
(see [`src/pressure.h`](src/pressure.h)):

```
P(kPa) = ((V_out / 3.3) - 0.05) * 100 / 0.9
```

All internal calculations use **kPa**. The ESP-NOW protocol exchanges values
as **percent (0–100)** of `MAX_KPA` (default 8.0 kPa). The PC never sees raw
ADC or kPa values.

## Tuning Constants (`src/main.cpp`)

| Constant | Default | Description |
|---|---|---|
| `MAX_KPA` | 8.0 | Hard safety cap in kPa — absolute burst protection |
| `DEFAULT_INFLATE_DUTY` | 255 | Pump PWM duty (0–255) for inflate/set_pressure |
| `PRESSURE_CHECK_MS` | 200 | Safety check interval (ms) |
| `STATUS_REPORT_MS` | 500 | Pressure status broadcast interval (ms) |
| `VALVE_SETTLE_MS` | 20 | Delay between closing one valve and opening the other (ms) |
| `PUMP_PWM_FREQ` | 20000 | Pump PWM frequency (Hz) — above audible range |

Per-chamber software limits can be set at runtime via `set_max_pressure`
(clamped to `MAX_KPA`). These survive until reboot.

## ESP-NOW Protocol

### Commands received from gateway

The gateway strips its own `"target"` field before forwarding.

| `cmd` | Fields | Description |
|---|---|---|
| `inflate` | `chamber` (0–2), `delta` (0–100, default 10) | Inflate by `delta`% relative to current pressure |
| `deflate` | `chamber` (0–2), `delta` (0–100, default 10) | Deflate by `delta`% relative to current pressure |
| `set_pressure` | `chamber` (0–2), `value` (0–100) | Inflate or deflate to an absolute target of `value`% |
| `set_max_pressure` | `chamber` (0–2), `value` (0–100, default 100) | Set per-chamber pressure ceiling (clamped to `MAX_KPA`) |
| `hold` | `chamber` (0–2) | Stop pump and close both valves — freeze at current pressure |
| `ping` | — | Responds `{"type":"pong"}` |
| `debug` | — | **(debug build only)** Responds with full node state snapshot |

#### Examples
```json
{"cmd":"set_max_pressure","chamber":0,"value":80}
{"cmd":"inflate","chamber":0,"delta":20}
{"cmd":"deflate","chamber":1,"delta":15}
{"cmd":"set_pressure","chamber":2,"value":75}
{"cmd":"hold","chamber":0}
```

### Status sent to gateway

Broadcast every `STATUS_REPORT_MS` (500 ms) for all 3 chambers:
```json
{"type":"status","chamber":0,"pressure":75}
```

### Debug response (debug build only)

```json
{"type":"debug","ch":[{"s":3,"kpa":2.4,"tgt":4.0,"max":8.0},...],"tx_ok":1520,"tx_fail":3,"drop":0,"up":342}
```

`s` = chamber state (0=idle, 1=pre-inflate, 2=pre-deflate, 3=inflating, 4=deflating),
`drop` = commands dropped due to queue overflow, `up` = uptime in seconds.

## Architecture

### Command queue

Commands are **queued** from the ESP-NOW callback (WiFi task) and processed in
`loop()` (Arduino task). This avoids blocking the WiFi stack — critical when
5+ nodes share the same gateway. The queue is a lock-free single-producer /
single-consumer ring buffer (16 slots).

### Non-blocking valve settle

When switching direction (inflate ↔ deflate) on a chamber, the old valve closes
and a settle timer starts. The new valve only opens after `VALVE_SETTLE_MS`
elapses in `loop()` — no `delay()` calls anywhere. Both valves are **never open
simultaneously** on the same chamber.

### Pump sharing

Multiple chambers can inflate/deflate simultaneously. The inflate pump runs at
`max(duty)` of all actively inflating chambers. The deflate pump runs at full
duty if any chamber is deflating. Pumps stop automatically when no chamber is
active.

## Debug vs Release builds

| Feature | Release | Debug |
|---|---|---|
| `Serial.begin()` | not called | initialized at 115200 |
| Serial log output | compiled out | state transitions, safety stops, commands |
| `onSent` callback | not registered | tracks `tx_ok` / `tx_fail` |
| `{"cmd":"debug"}` | unknown command (ignored) | returns full state snapshot |
| Queue drop counter | not tracked | counted in `cmdDropped` |
| Compiler flags | `-O2 -DNDEBUG` | `-O0 -g -DDEBUG_BUILD` |

## Performance notes

- **Non-blocking loop** — no `delay()` anywhere; valve settle uses timestamps.
- **Cached ADC readings** — pressure read once per `PRESSURE_CHECK_MS`, reused
  by both safety checks and status broadcasts.
- **Unified pump recalc** — single `recalcPumps()` iterates chambers once for
  both inflate and deflate pumps.
- **`snprintf` for status messages** — fixed-format JSON written directly into
  stack buffers; no ArduinoJson heap allocation for outgoing packets.
- **LEDC channels:** inflate pump on channel 0, deflate pump on channel 1.
  PWM at 20 kHz — above audible range.

## Important caveats

- ESP-NOW and WiFi share the same radio. The node runs in `WIFI_STA` mode
  **without** connecting to an AP (channel 1 by default). The gateway must be
  on the same WiFi channel.
- Maximum ESP-NOW payload: **250 bytes**. Status messages are ~48 bytes.
- ADC pins 34, 35, 32 are **input-only** on the ESP32 (no pull-up/pull-down
  support). Ensure the sensor output is within 0–3.3 V.

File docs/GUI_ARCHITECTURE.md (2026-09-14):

# GUI architecture & conventions

## Layering: keep domain logic out of dialogs

GUI files should be presentation + wiring; the rules (validation, config
building, persistence, hardware orchestration) belong in a Qt-free layer that is
unit-testable without a screen. The domain layers are `src/core/`,
`src/hardware/`, `src/robots/`, `src/activities/`, `src/data/` - `core/` is not
the only one, which is why it is small.

Worked example: `src/core/skin_config.py` holds the skin-entry rules (node
lookup, validation, `build_skin_entry`, save/delete on the settings tree) as
pure functions over the plain `settings.data` dict. `SkinConfigDialog` calls into
it and keeps only widgets + `QMessageBox` text. Tests:
`tests/test_skin_config.py`. The same pattern applies to the other fat dialogs
(`session_panel`, `robot_panel`) if/when they are refactored.

## Layouts are `.ui` files

Author layouts as Qt Designer `.ui` in `src/gui/ui/`, compile with
`scripts/compile_ui.sh` (-> gitignored `src/gui/ui_*.py`, regenerated by CI which
globs `src/gui/ui/*.ui`). Never hand-build a layout in Python. Every control
gets a `whatsThis` (feeds the "?" help mode; `toolTip` is the fallback).

**Known debt (existing exceptions, do not copy):** a few controls are still
added in Python on top of their `.ui` and should move into it when those files
are next touched:

- `main_window.py` - most **Tools** menu actions (Activity Editor, Update Nodes
  (OTA), Touch Gestures, Touch Position Bench, Calibrate Fill Times, Calibrate
  Touch Coupling, Emergency Flash) are `QAction`s created in `__init__`.
- `session_setup_dialog.py` - the simulation-mode and record-sensor-streams
  checkboxes.
- `settings_dialog.py` - the "SoftEdIBO Gateway" and "Recordings" groups
  (`_build_gateway_section` / `_build_recordings_section`).

### The `monitor/` subpackage

Live monitor widgets (`src/gui/monitor/`) used to be hand-built in Python because
they are dynamic/QPainter. They now follow the `.ui` rule too:

- **Form/display panels** are `.ui`: `chamber_widget.ui`,
  `touch_tuning_panel.ui`. The Python class multiply-inherits
  `(QWidget/QGroupBox, Ui_X)` and calls `setupUi(self)`.
- **QPainter canvases are promoted widgets**. The painter class lives in its
  own module (`monitor/pressure_bar.py:PressureBar`) so the generated `ui_*`
  can `import` it without a circular import, and the `.ui` promotes a
  placeholder to it via
  `<customwidget><header>src.gui.monitor.pressure_bar</header>`. Promoted
  widgets are built by `setupUi` with the **default constructor**, so they take
  no required args. (The same mechanism promotes `HelpButton` from
  `src/gui/help_mode.py` in `observer_panel.ui`.)
- **Dynamic containers** (`skin_widget`, `robot_monitor_widget`,
  `robot_monitor_panel`, `organ_panel`) stay hand-built: they populate children
  in runtime loops, so a `.ui` would only hold an empty shell.

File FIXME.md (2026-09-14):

# FIXME - Actuator (pumps + valves) logic

Status tracker for the actuator chain (PC -> gateway -> node -> pumps/valves).
The layer-by-layer dissection this file used to hold described the
pre-redesign code and is obsolete: the control logic was redesigned around the
shared **coupled-fill supervisor** (`firmware/common/coupled_fill.h`, both
boards) with progressive close. The current design, its diagnostics and its
safety caps are documented in `docs/COUPLED_FILL_CONTROL.md` and
`docs/PRESSURE_AND_FILL_SAFETY.md`; this file now only tracks what is still
open.

## STATUS (2026-07-05)

The 2026-06-26 PC-side fixes (see Resolved) did not make the chain work on
their own - the real faults were per-chamber closed-loop control over
**coupled** sensors (shared manifolds, no check valves) and a `millis()`
underflow that force-stopped rounds the instant they opened. Both are fixed by
the engine redesign (see the docs above). What remains is hardware validation
plus the known gaps below.

## Open

- [ ] **Bench-validate the progressive-close firmware on hardware, both
      boards.** Confirm the boot marker in the log after flashing -
      `"fw":"estop-1-sw02"` (direct) / `"fw":"estop-1"` (multiplexed) (OTA
      sends the prebuilt
      `firmware/node_actuator/firmware-*.bin`; rebuild them with
      `scripts/build-firmware.sh` - building into `.pio/` alone is not enough).
- [ ] **`duty` is not honoured on the engine path.** Both boards parse and
      store the optional pump `duty` on inflate/deflate/set_pressure, but
      `recalcPumps()` never uses it (full duty, except the `hold_duty` servo
      and the below-floor deflate pull) (an earlier duty-aware version
      regressed the pump and was reverted). The PC's gentle-fill plumbing
      (`set_pressure(period_ms=...)` -> `duty_for_period` / `DutyModel`) therefore
      has no firmware effect today; only the direct board's bench `test_run`
      honours `duty` (which is what the duty-curve calibration sweep uses).
      Decide: re-add duty-aware pumps safely, or drop the runtime duty path.
- [ ] **The multiplexed board lags the direct board's command set:** no
      `test_run`/`test_stop` (continuous bench run), no `status_rate` fast
      telemetry (`FastTelemetry`), no `pumps`/`seq` frames, and no seq-less
      `stop`/`resume`/`tare` acks (it does ack `set_max`/`set_min` with a
      `seq`, like the direct board). Continuous fill / duty-curve /
      deflate-curve calibration is direct-only until ported, so the GUI
      disables Calibrate Fill for `node_multiplexed` chambers.
- [ ] **Manual-vs-engine pump arbitration on the direct board.** Mostly
      resolved (`valve_manual` drops the chamber from the engines, the bench
      test owns the hardware exclusively, pumps follow the ACTUAL valve
      mirror), but a `pump_manual` ON is still silently overwritten by the next
      engine `recalcPumps()`. The multiplexed board suspends autonomous control
      under a `manualActive` latch; the direct board has no equivalent.
- [ ] **Command ACK reliability.** `set_max/min_pressure` are confirmed
      end-to-end on BOTH boards (`seq` + `ackConfirmable` ->
      `se::node::sendAck`; PC `CommandConfirmer` retransmits). Still TODO:
      seq-confirmed `stop`/`resume`/`configure` (the direct board acks
      stop/resume without a `seq`, the multiplexed board not at all) and the
      blanket Tier-1 gateway retry. The actuation commands stay
      fire-and-forget by design; the pre-actuation limit re-push
      (`Skin._push_limits`) remains as a backstop - `docs/ACK_RELIABILITY.md`.

## Resolved (kept for the record)

| What | Resolution |
|---|---|
| `firmware/common/fill_control.h` orphaned since the engine redesign (dead `MAX_FILL_MS`/`fillTimeTick`, lost idle leak top-up `maintainTick`/`hold_kpa`) | Header deleted. Leak maintenance was reimplemented engine-aware as the `hold_duty` regulated hold (`firmware/common/hold_duty.h`, both boards; auto-hold after every inflate/deflate). |
| Whole-skin vent alternated `valve_manual` sides (the boards only keep one side open at a time) | Fill calibration, Skin Config -> Zero Sensors and the Test Actuators Vent button now send the firmware `vent` command (both valves open, pumps kept off). |
| STOP ALL didn't stop (the dialog auto-`resume`d, discarding the firmware latch; a lost `stop` frame left the actuator running) | `_stop_all` latches (sends `stop` x3, no auto-resume) and re-arms lazily; the firmware `stop`/`resume` latch on BOTH boards re-asserts all-off every loop while latched. App-wide: the "0" panic key + the menubar E-stop button latch every robot (`src/gui/main_window.py`). |
| Test dialog / fill calibrator sent `value=255`, which the firmware ignores (`inflate` reads `delta`, default 10 %) | Both now send `delta=100`; the test dialog documents the field choice inline. |
| Stale `pins.h` pump comment (claimed PUMP1=IO33) | Comment fixed and bench-verified: `PUMP_PINS={32,33}`, PUMP1=IO32 (inflate), PUMP2=IO33 (vacuum). Pumps confirmed physically working - which also closes the DRV3297-enable question. |
| Pressure-based inflate self-cancelling on a bad/laggy sensor reading | Superseded by the engine: median-of-3 reads, per-chamber cutoff debounce, min-round spike gate; the hard kPa caps moved to +/-100 (effectively uncapped) so the unreliable gauge cannot gate fills - over-pressure is time-bounded instead (`capMs`/`chamber_max_ms`/`seq_max_ms`/watchdog). |
| The old section 11 "time-based calibrated control" redesign plan | Superseded by what actually shipped: measured fill curves (`FillProfile`, per-combination `fill_profiles`, per-type templates `fill_profiles_by_type`), falling deflate curves (`DeflateProfile` + floor-aware time budgets), duty sweeps (`DutyModel`), and the engine's per-chamber `capMs`. The planned idle resync is moot: the PC recomputes fill % from the live `kpa` on every status frame (`src/hardware/units.py` `kpa_to_pct`) instead of dead-reckoning elapsed time. |

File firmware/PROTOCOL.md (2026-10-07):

# SoftEdIBO ESP-NOW Protocol

Three firmware flavors share this protocol:

- **`node_direct`** - 3 chambers, GPIO valves, onboard pumps (optionally folds
  in the magnet/touch module, auto-detected).
- **`node_multiplexed`** - up to 12 chambers, multiplexed valves/sensors,
  shared pump banks (no reservoir tanks in the current build - pumps push
  straight into the chambers).
- **`node_magnet_sensor`** - 4x MLX90393 magnet/touch board (+1 optional 5th
  sensor; separate firmware, no chambers / pumps; streams sensor data only).

The gateway is mostly a **transparent bridge** between the PC (USB serial) and
the nodes (ESP-NOW) - it rewrites the JSON envelope and forwards the payload
unchanged:

- **PC -> Gateway**: payload with `target` (MAC of the destination node)
- **Gateway -> Node**: same payload without `target`, sent over ESP-NOW
  (paced on TX-done via `se::sendPaced`, so command bursts don't overrun the
  radio TX queue; there is still no retransmit)
- **Node -> Gateway**: any JSON payload
- **Gateway -> PC**: same payload with `source` (sender MAC) added

Two envelopes are NOT relayed to ESP-NOW nodes:

- **No `target`** - the command is for the gateway itself (`get_ap`, `set_ap`,
  `ota_store_*`); see [`gateway/README.md`](gateway/README.md).
- **`target:"thymio"`** - forwarded over UART to the companion ESP32-C6 radio
  co-processor that speaks 802.15.4 to Thymio robots (`thymio_*` commands);
  its replies come back tagged `"source":"thymio"`. See
  [`../docs/THYMIO_WIRELESS_CONTROL.md`](../docs/THYMIO_WIRELESS_CONTROL.md).

The only messages the gateway emits on its own are the gateway-local replies
above and the lines listed at the bottom of this document.

---

## PC -> Gateway -> Node - commands

Each command is sent on the serial line as
`{"target":"<mac>", "cmd":"<name>", ...}`.

### Common to both actuator node types

`chamber: -1` fans an actuation command out to **every** chamber in one frame
(the PC's Inflate/Deflate-All), so a single dropped per-chamber frame can't
leave part of the skin un-actuated. Limit commands (`set_max_pressure` /
`set_min_pressure`) stay single-target.

Fills are driven by the shared **coupled-fill engine**
([`common/coupled_fill.h`](common/coupled_fill.h)): co-active same-direction
chambers open together, each closes progressively the moment the shared line
reaches its target, then one settle + isolated verify round. Safety is
time-based: per-chamber open cap 5 s (overridable per request via `ms`),
per-round 6 s / whole-sequence 25 s on the direct board and 8 s / 45 s on the
multiplexed board (`direct/chambers.h`, `multiplexed/chambers.h`), plus a 10 s
actuation watchdog.

`chamber: -1` on `inflate`/`deflate` carries the request's `ms`/`duty`/`timed`
to every chamber on both boards. A chamber index outside the board's valid
range (`0..2` on the direct board, `0..num_chambers-1` on the multiplexed
board) is rejected - it no longer wraps to `-1` (all); a rejected
`set_max_pressure`/`set_min_pressure` that carried a `seq` is NACKed with
`err:"bad_chamber"`, anything else is dropped silently.

**While emergency-stopped** (`stop` received, no `resume` yet) both boards drop
every actuation command (`inflate`, `deflate`, `set_pressure`, `hold`,
`hold_duty`, `valve_manual`, `pump_manual`, `vent`, `test_run`), so nothing is
queued to run on re-arm. `set_max_pressure`/`set_min_pressure` still apply
(and ack) because they only store a limit. `ping`, `tare`, LED commands,
`configure` (multiplexed setup / magnet tuning), `rebaseline` and the direct
board's `test_stop`/`status_rate` stay honoured.

| `cmd` | Fields | Notes |
|---|---|---|
| `ping` | - | `target:"FF:FF:FF:FF:FF:FF"` does a broadcast scan; reply carries `rgbw` + `kpa_min` |
| `inflate` | `chamber` (-1 = all), `delta` (0-100 %), `ms`?, `duty`?, `timed`? | Target = current + `delta` % of the [min, max] range, clamped to max; no-op if already at/above target. `ms>0` bounds that chamber's total valve-open time - the closing authority for a target the gauge can't see; 0/omitted keeps the engine's 5 s cap. `timed:1` = the board has NO pressure sensor populated: run fully open-loop on `ms` (required) and ignore the floating gauge entirely (no below-target guard, no cutoff, no measure) |
| `deflate` | `chamber` (-1 = all), `delta` (0-100 %), `ms`?, `duty`?, `timed`? | Mirror of `inflate` (target clamped to min). A target below the sensor floor (`kpa_min`) can only close on `ms` (calibrated deflate curve) or the engine's time cap; once the chamber's reading has bottomed out at the floor the pull continues on time with the vacuum pump dropped to the shared 180 PWM floor (full again the moment any open deflate valve is still visible / opened by hand). `timed:1` as on `inflate` - without it a sensorless board's below-target guard drops the deflate outright (a blind chamber never reduces: it stays at full duty for its `ms`) |
| `set_pressure` | `chamber` (-1 = all), `value` (0-100 %), `duty`? | Routes through the engine as an inflate or deflate to the absolute target |
| `set_max_pressure` | `chamber`, `value` (kPa), `seq`? | Stored on the chamber until reboot. With an optional `seq` the node confirms it (see `ack` below) so the PC can retransmit a dropped safety limit instead of clamping to a stale ceiling |
| `set_min_pressure` | `chamber`, `value` (kPa), `seq`? | Same confirmed-delivery option as `set_max_pressure` |
| `hold` | `chamber` (-1 = all) | Closes valves, drops the chamber from both engines (and from any `hold_duty`) |
| `hold_duty` | `chamber` (-1 = all), `duty` (0 or 70-255), `kpa`?, `dir`?, `timed`?, `off`? | Leak-compensating regulated hold on the chamber's own gauge, from the losses it measures in real time. `dir` 0 (default) = pressure hold: INFLATE valve + pressure pump; `dir` 1 = vacuum hold: the mirror with the DEFLATE valve and the vacuum pump. CLOSED FIRST: the hold starts with the valve closed measuring the chamber's closed-valve loss (kPa/s); a tight chamber stays closed and unpumped; only a chamber that has drifted 0.25 kPa below its target opens (a fresh hold waits up to 600 ms for its first loss window first). CONTINUOUS DUTY: once open the valve STAYS open and the shared pump PWM is the regulator, `ff + kp * predicted deficit +- 4 dither`, servoed down to the 70 PWM RUN floor (`pump_duty::RUN_MIN`) - not the 180 START floor (`pump_duty::MIN`), which only the KICK on every pump start uses (80 ms, then a 2 PWM/ms descent). `ff` is the predicted equilibrium duty: a least-squares line `slope = a*duty + b` over the last 16 windows of 200 ms (mean duty, reading slope) gives the pump gain `a` and the open-line loss `b`; `ff = -b/a` is where delivery balances loss (trusted with >= 4 PWM^2 of duty spread and a positive gain; the dither keeps it identifiable at equilibrium; `kp = 2 s^-1 / a` clamped 5..30, default 15 PWM/kPa). Until trusted, `ff` walks by a bounded integral of the predicted deficit (40 PWM/s, <= 12 per window), primed by `duty` when given, else predicted from the measured closed loss (run floor + 20 PWM per kPa/s). The deficit acted on is the reading extrapolated 80 ms ahead. A running pump that stops delivering under the start floor (reading falls 600 ms while air is needed) raises the side's learned run floor by 12 and re-kicks. THE ONLY PULSE LEFT: the valve closes (2-tick debounce, 160 ms minimum open) only when the pump sits on the run floor (predicted `ff` there, or the command there 400 ms with the reading not falling) and the chamber is at / heading past its target - or when it is 1 kPa past it with the command on the floor. A leaky chamber then re-opens 0.25 kPa below target at the run floor duty (the physical limit of a pump that cannot trickle slower); a tight one stays closed. One target level per line: chambers whose targets differ by more than 0.5 kPa never share it - a chamber at another level waits while the line's chambers still need air and gets the line once they sit at their targets (a starving line admits everyone). A vacuum target below the gauge floor (blind 0..100 sensor) is held by timed re-pulls instead: 120 ms at `duty` (>= 180) every 2.5 s, plus an immediate pull whenever the chamber leaks up into the visible band. `duty` 0 = no seed (the node predicts its own); otherwise it seeds the servo (or is the re-pull duty). `timed:1` (or no `kpa`) keeps the valve open at `duty` (sensorless boards). Pumps off whenever no held valve of their side is open. PC must re-send ~2 s as keepalive (6 s dead-man drops the hold). `off:1` drops it. Any inflate/deflate/set_pressure/hold on the chamber supersedes it; fill engines/manual/bench runs suspend it and it resumes after |
| `stop` | - | Emergency stop: latch every pump off + valve closed; actuation commands are dropped until `resume` (limits still apply - see above) |
| `resume` | - | Re-arm after `stop` |
| `tare` | - | Zero the pressure sensors: capture each chamber's current reading (8-sample average) as its ambient zero and persist it in NVS. Non-actuating, honoured while stopped. The PC vents every chamber first (`vent`, Skin Config -> Zero Sensors). The direct board acks it (`{"type":"ack","cmd":"tare"}`); the multiplexed board does not, and bypasses the `configure` requirement for it |
| `valve_manual` | `chamber`, `side` (0 = inflate, 1 = deflate), `open` (0/1) | Dev/bench override, bypasses the engine; 5 s dead-man auto-off + hard-limit cutoff |
| `pump_manual` | `pump` (0 = inflate/pressure, 1 = deflate/vacuum), `on` (0/1) | Dev/bench override, same safety nets |
| `vent` | `chamber` (-1 = all), `open` (0/1) | Bench vent: BOTH valves of the chamber open with the pumps kept off it (excluded from the pump recalc), so it equalises to atmosphere - neutralises an inflated or vacuumed chamber and drops any `hold_duty` on it. Manual-override rules: 5 s dead-man (PC keeps it alive), a `valve_manual` open on either side or any actuation ends it |
| `set_led` | `color` ("#RRGGBB"), `pattern` ("off"/"solid"/"blink"/"pulse"/"comet"/"fade"), `color2`?, `period_ms`, `count`, `fade_ms`?, `angle`?, `index`?, `ring`? | WS2812/SK6812 ring(s). `index` sets a single pixel; omit it for the whole ring. `period_ms`/`count` apply to blink/pulse/comet/fade (count <= 0 = forever). `"fade"` cross-fades `color` <-> `color2` (default black) on the node, one full cycle per `period_ms`. Every change cross-fades over `fade_ms` (default 250 ms; 0 snaps). `angle` (0-360 deg) rotates the comet start. `ring` (0..2) selects one of the multiplexed board's three rings; omit/-1 = all (ignored by the direct board) |
| `set_led_halves` | `colors` (["#RRGGBB", ...], up to 8), `pattern`, `period_ms`, `count`, `fade_ms`?, `angle`?, `ring`? | Splits the ring into `len(colors)` equal contiguous arcs in ONE frame (e.g. half purple / half yellow), rendered from loop(). `pattern`/`period_ms` animate the whole split together; `"comet"` paints one comet per colour. `angle` rotates the split. Prefer this over a burst of per-pixel `set_led` frames - those call `strip.show()` once per pixel in the receive task and reset the node |
| `debug` | - | Debug build only; reply: `{type:"debug",...}` |

`duty` (1-255) is an optional pump PWM value: it is parsed and stored, but the
shared-manifold pump recalc currently runs the pumps at full duty - only the
bench `test_run` honors it (duty-curve calibration sweeps).

### Direct-node only

| `cmd` | Fields | Notes |
|---|---|---|
| `test_run` | `dir` (0 = inflate, 1 = deflate), `chamber`? (-1 = all), `duty`? | Continuous bench run: latches one pump + its valve(s) open, ignoring pressure. Re-send ~1 Hz as keepalive - a 3 s dead-man stops the run if the link drops |
| `test_stop` | - | End the bench run (honoured even while `stop`ped) |
| `status_rate` | `ms`, `ttl` | Fast telemetry: lower the `status` cadence to `ms` (floor 20 ms) for a `ttl`-bounded window; auto-reverts to 500 ms when the ttl lapses. `ms<=0` / `ttl<=0` reverts immediately |
| `rebaseline` / `configure` | (see magnet table below) | The direct board folds the magnet/touch module in (auto-detected; no-op when no sensors are wired) |

### Magnet/touch commands (node_magnet_sensor + direct board's folded-in module)

| `cmd` | Fields | Notes |
|---|---|---|
| `rebaseline` | - | Re-zero (recapture the baseline of) all magnetic sensors |
| `configure` | `act_threshold_ut`, `adaptive_baseline`, `baseline_tau_ms`, `stream_vec`, `osr`, `filter` | Set the uT activation threshold; opt-in adaptive baseline (tracks slow drift, frozen per-sensor while active); `stream_vec` toggles the 3-axis `vec` rows in the stream (RAM-only - re-send after a node reboot). `osr` (0-3) / `filter` (0-7) set the MLX90393 oversampling / digital filter (Adafruit enum indices; applied from the main loop, then the baseline is re-captured - keep hands off the skin). All optional. Legacy `fullscale_mt`/`act_threshold` (fraction) still accepted |

### Multiplexed-node only

#### `configure`

Required before any actuation command (`ping`, `stop`/`resume`, `debug`,
`tare` and `hold_duty` work regardless). Without it, the node replies
`{type:"error", reason:"not_configured"}`. Re-send to change any field at
runtime.

Fields (all optional - omitted ones keep their current firmware state):

- `num_chambers`
- `pump_inflate_count`
- `pump_deflate_count`
- `pump_groups` - `{pressure:[i,...], vacuum:[i,...]}`, indices 1..6 of
  `PUMP1..PUMP6`; overrides the boot default (first half pressure, second half
  vacuum). Wins over the count fields when both are present.
- `organ_channels` - `[c, ...]` mux channels carrying organ+cover circuits; the
  index in this list becomes the `slot` in the node's `organ` broadcasts. Wire
  them to the highest channels (I13..I15) so the chamber autodetect (which
  claims low channels first) doesn't collide. Up to 4. Applying this also
  scrubs those channels from any autodetected chamber/tank assignment.
- `tank_pressure_min/max/target_kpa`, `tank_vacuum_min/max/target_kpa` -
  legacy reservoir-tank bounds. Still parsed and stored, but the current
  no-reservoir build has no tank sensors and nothing consumes them (the pumps
  push straight into the chambers); the PC no longer sends them.

---

## Node -> Gateway -> PC - replies and broadcasts

Each message arrives on the PC with a `source` field added by the gateway.

### Common to both actuator node types

| `type` / `status` | Fields | When |
|---|---|---|
| `status:"node_*_ready"` | `fw`, `rgbw`, `kpa_min` | Once at boot, ESP-NOW broadcast to `FF:FF:FF:FF:FF:FF` |
| `status` | `kpa[]` (kPa, 0.1 resolution), `st[]` (actuation: 0 idle, 1 inflating, 2 deflating), `vi[]`/`vd[]` (actual inflate/deflate valve output, 0/1) - parallel arrays indexed by chamber | ONE batched frame per node every 500 ms covering all chambers (3 on the direct board, `num_chambers` on the multiplexed board). No `pressure` % - the PC recomputes it from `kpa` against the configured range. The direct board also emits one the instant a chamber's state or valve output changes, sends faster during a `status_rate` window, and keeps reporting while stopped. The multiplexed board refreshes idle chamber pressure every `PRESSURE_CHECK_MS` (200 ms) so `kpa` stays live, but sends **no** status while emergency-stopped, unconfigured, not ready or in the PCA error state |
| `pong` | `rgbw`, `kpa_min` | Reply to `ping` |
| `ack` | `cmd`, `seq`?, `chamber`?, `ok`?, `err`? | Confirms a command was **applied**. **Both boards** ack `set_max_pressure`/`set_min_pressure` when the PC tagged them with a `seq`, echoing `seq`+`chamber`+`ok` (`ok:false`+`err`, e.g. `"bad_chamber"`, is a NACK) so the PC can retransmit a dropped safety limit - see [`../docs/ACK_RELIABILITY.md`](../docs/ACK_RELIABILITY.md). The direct board additionally acks `stop`/`resume`/`tare`/`test_run`/`test_stop`/`status_rate` (no `seq`) |
| `pumps` | `inf`, `def` (live pump PWM duty, 0-255) | Direct board only: with every status batch + the instant a duty changes |
| `seq` | `inf_ph`/`inf_mask`, `def_ph`/`def_mask`, `ch[]` (`k`, `mx`) | Direct board only: engine-phase diagnostic after an Inflate/Deflate-All |
| `dbg` | `ev` (`"rx"`/`"eng"`/`"dry"`), ... | Debug build only: valve-state-at-command, engine round/measure trace, dry-pump warnings |
| `debug` | (per-node - see below) | Reply to `debug`, debug build only |

The boot announce is `{"status":"node_<type>_ready", ...}` (e.g.,
`node_direct_ready`, `node_multiplexed_ready`, `node_magnet_sensor_ready`). It
is broadcast on the ESP-NOW channel so the gateway can forward it before the
node knows the gateway's MAC. Actuator boards add:

- `fw` - build marker string, to confirm from the PC log which firmware
  actually booted;
- `rgbw` - whether the LED ring build is RGBW (`-DLED_RGBW`), so the OTA
  picker auto-selects the right bin;
- `kpa_min` - the gauge floor (lowest pressure the sensor can see; build flag
  `SENSOR_KPA_MIN`), so the PC knows when a deflate needs a time budget.
  `rgbw`/`kpa_min` are repeated in every `pong` for PCs that missed the boot.

### `organ` - organ network + silicone cover state (direct + multiplexed)

```json
{"type":"organ", "resistance_ohm": 952.4, "open": false}          // direct
{"type":"organ", "slot": 0, "resistance_ohm": 952.4, "open": false}  // multiplexed
```

An ADC line measures the parallel resistance of all plugged-in organs of one
circuit; the silicone cover closes the circuit's return path, so an open
circuit means the cover is off (`open: true`, `resistance_ohm: -1`). Sent on
change (+/-25 ohm hysteresis, 3-sample debounce on the open/closed flip - the
cover rests by gravity) and re-sent every 2 s as a heartbeat.

- **Direct node**: a single circuit on `ORGAN_SENSE_PIN` (IO36). No `slot`
  field (treated as `slot 0`).
- **Multiplexed node**: one circuit per `organ_channels` entry (see
  `configure`); `slot` = index in that list. Lets one node serve several
  independent patients (e.g. one per Tree branch).

On the PC, `ESP32Controller.on_organ(cb)` delivers `(resistance_ohm, slot)`
(`inf` when open); `src/hardware/organ_sensor.py` follows one slot and splits
it into cover / resistance event streams for activities.

### `button` - push button (direct)

```json
{"type":"button", "pressed": true}
```

An active-low push button on `BUTTON_PIN` (IO36, the same line as the organ
circuit; the pin has no internal pull-up, so the board provides one). Sent on
every debounced press/release (3 samples at 10 ms, edges at least 50 ms
apart) and re-sent every 2 s as a heartbeat.

On the PC, `ESP32Controller.on_button(cb)` delivers `pressed`; behaviours
read it through the `button_pressed` / `button_count` conditions.

### Multiplexed-node only

| `type` | Fields | When |
|---|---|---|
| `error` | `reason` | On error (see list below) |

`error.reason` values: `pca9685_address_conflict`, `not_configured`.

(The old `tank_status` broadcast is gone - the current no-reservoir build has
no tank sensors.)

### magnet sensor-node only

#### `magnet` - live sample (every reading)

| Field | Shape |
|---|---|
| `mag` | `[m1, ...]` - N per-sensor magnitudes (uT), baseline-subtracted |
| `act` | `[idx, ...]` - indices of sensors whose `mag >= act_threshold_ut` |
| `vec` | `[[dx,dy,dz], ...]` - per-sensor 3-axis deltas in uT: one decimal (0.1 uT) for components below 100 uT, whole uT above; only when 3-axis streaming is on (`MAG_VECTOR` build or `configure stream_vec`). The announce then carries `"vec":1` |

Cadence: ~28 Hz (35 ms) on the standalone board; 100 ms (~10 Hz) on the direct
actuator board, so the stream can't crowd out actuation commands. The magnet
module is shared: `firmware/common/se_magnet.h`, used by both the standalone
`node_magnet_sensor` board and the direct actuator board (which folds it in,
auto-detected).

The PC decides what's touched based on the skin's configured layout
(`skin.touch.sensor_grid` paired with `magnet_geometry`). The firmware does
**not** emit `predicted_quadrant` / `active_quadrants` - those are computed on
the PC.

Register `controller.on_magnet(cb)` to receive each message (the gateway adds
`"source":"<MAC>"`).

> **Sizing**: stay under ~230 bytes total (ESP-NOW packet limit 250). Drop
> `device_id` and `ts_ms` - `source` is added by the gateway and the PC
> stamps on receipt.

#### Boot announce (self-describing)

The magnet sensor firmware broadcasts its configuration at the end of
`setup()` (and re-broadcasts every 2 s until the gateway is known, so a
late-connecting PC still captures it):

```json
{"status":"node_magnet_sensor_ready", "sensors": 4, "variant": "mlx90393", "fw": "magvec-1"}
```

`fw` is the magnet module's build marker; `"vec":1` is added when 3-axis
streaming is on (from boot on the `vector` env / `-DMAG_VECTOR` build, or after
`configure stream_vec:true`). A `ping` to the standalone board gets a bare
`{"type":"pong"}` (no `rgbw`/`kpa_min` - it has no LEDs or chambers). `ESP32Controller` caches
the payload on receipt (including the optional `magnets`/`geometry` keys,
which the current firmware does not emit yet); read it later via
`controller.magnet_geometry`.

#### Linking a skin to a magnet sensor node

A skin's YAML may opt into touch sensing by adding a `touch` block referencing
the magnet sensor node's MAC (see the annotated example in
`config/settings.yaml`):

```yaml
skins:
  - skin_id: belly
    chambers: [...]
    grid: {cols: 8, rows: 4}
    chamber_grid: [[...rows of chamber-index-or-(-1)...]]
    touch:
      node_mac: "BB:CC:DD:EE:FF:00"
      sensor_count: 4
      grid: {cols: 8, rows: 4}          # optional separate sensor-grid dims
      sensor_grid: [[...rows of sensor-index-or-(-1)...]]
      sensor_to_chamber: {"0": 0, "1": 0, "2": 1}   # optional touch routing
```

Skins without a `touch` block remain pure pneumatic (the existing case);
nothing else changes.

### `debug` reply payloads

**node_direct** (debug build only):

- `num_chambers`
- `ch[]` - array, one entry per chamber, each with
  `s` (state code), `kpa`, `tgt` (target kPa), `min`, `max`
- `tx_ok`, `tx_fail` - ESP-NOW send counters
- `drop` - commands dropped by the queue
- `up` - uptime in seconds

**node_multiplexed** (debug build only):

- `ready`, `configured` - booleans
- `num_chambers`
- `p_tank`, `v_tank` - mux channel indices assigned by autodetect

### OTA firmware update (all ESP-NOW nodes)

Every node includes the shared receiver [`common/se_ota.h`](common/se_ota.h);
the PC side is `src/hardware/node_ota_updater.py` (ESP-NOW) and
`src/hardware/wifi_ota_updater.py` (WiFi), driven from Tools -> Update Nodes
(OTA)... The gateway relays these unchanged.

| Direction | Payload | Notes |
|---|---|---|
| PC -> node | `{"cmd":"ota_begin","size":N,"md5":"<hex>","chunk":96}` | Starts an image; node replies `ota_ready` or `ota_error` (`begin_failed`) |
| PC -> node | `{"cmd":"ota_data","seq":S,"data":"<base64>"}` | One chunk, `seq` 0,1,2,... `CHUNK_SIZE` = 96 raw bytes (the gateway->node relay drops payloads over ~190 B). Node writes only the expected `seq`, re-acks older ones, silently drops future ones |
| PC -> node | `{"cmd":"ota_end"}` | Node verifies the MD5, arms an RTC "boot done" flag and reboots |
| PC -> node | `{"cmd":"ota_wifi","ssid":"...","pass":"...","url":"http://.../fw"}` | Fast path (S3 gateway with PSRAM): node leaves ESP-NOW, joins the gateway SoftAP and HTTP-pulls the image staged via `ota_store_*`. The gateway injects its own `ssid`/`pass` when absent |
| node -> PC | `{"type":"ota_ready"}` | Reply to `ota_begin` |
| node -> PC | `{"type":"ota_ack","seq":S}` | Chunk `S` written (or already held) |
| node -> PC | `{"type":"ota_wifi_start"}` | `ota_wifi` accepted; the node is going off the air |
| node -> PC | `{"type":"ota_done"}` | Broadcast 4x by the **new** firmware after it boots - the only success signal (both paths) |
| node -> PC | `{"type":"ota_error","reason":"..."}` | `begin_failed`, `not_active`, `bad_data`, `write_failed`, `verify_failed`, `bad_wifi_args` |

A failed WiFi join/download reboots the node back into its current firmware.
See [`gateway/README.md`](gateway/README.md) for the gateway-local
`ota_store_*` staging commands.

### Non-JSON node output

If a node sends a payload that is not valid JSON, the gateway forwards it
wrapped as `{"source":"<mac>", "raw":"<bytes>"}`.

### Local Serial output (NOT forwarded by gateway)

Printed on the node's USB Serial only - only visible if you connect a USB
cable to the node and open `pio device monitor`.

| Payload | Node | Build |
|---|---|---|
| `{"status":"node_*_ready"}` | both | Always (mirrors the ESP-NOW broadcast) |
| `{"error":"esp_now_init_failed"}` | both | Always, if `esp_now_init()` fails |
| `TODO: ...` autodetect lines | node_multiplexed | Always |
| `VALVE ...` / `PUMPS ...` / `RX ...` lines | both | Debug only |

---

## Gateway internal messages

Emitted on the serial line by the gateway itself, no `source` field.

| Payload | When |
|---|---|
| `{"status":"gateway_ready", "mac":"<own_mac>", "ap":"<ssid>"}` | Boot succeeded (`ap` on the SoftAP build) |
| `{"error":"esp_now_init_failed"}` | `esp_now_init()` failed at boot |
| `{"type":"error", "reason":"bad_cmd_json", "len":N, "raw":"..."}` | A PC line failed to parse (usually USB byte loss) - reported instead of silently dropped |

Gateway-local command replies (`ap_config`, `ap_set`, `ota_store_*`) are
documented in [`gateway/README.md`](gateway/README.md).

---

## Source files

- Shared ESP-NOW/MAC/radio layer - [`firmware/common/se_espnow.h`](common/se_espnow.h)
- Shared coupled-fill supervisor - [`firmware/common/coupled_fill.h`](common/coupled_fill.h)
- Shared magnet/touch module - [`firmware/common/se_magnet.h`](common/se_magnet.h)
- Shared OTA receiver (ESP-NOW + WiFi pull) - [`firmware/common/se_ota.h`](common/se_ota.h)
- Gateway dispatch - [`firmware/gateway/src/main.cpp`](gateway/src/main.cpp)
- node_direct command parser/handler - [`firmware/node_actuator/src/direct/commands.h`](node_actuator/src/direct/commands.h)
- node_multiplexed command parser - [`firmware/node_actuator/src/multiplexed/main.cpp`](node_actuator/src/multiplexed/main.cpp) (`parseAndQueue`, `processCommand`)
- node_magnet_sensor / touch board (MLX90393) - [`firmware/node_magnet_sensor/src/main.cpp`](node_magnet_sensor/src/main.cpp)

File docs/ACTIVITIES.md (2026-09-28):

# Activities & Behaviors

Living document - describes the **current** Activity system (what's shipped),
plus the original phased plan for the behavior framework (kept for design
rationale; several parts were later superseded).

The framework was delivered in phases:

| Phase | Goal | Status |
|---|---|---|
| 1a | Documentation + design alignment | **done** |
| 1b | DB-backed activity presets + tunable params + auto-generated GUI | **done**, later removed - behaviours replaced presets (see below) |
| 1c | Organ Swap activity skeleton (mocked hardware) | **done**, later removed - see below |
| 1d | Firmware extensions: organ ADC + LED + Python wrappers | **done** (`organ.h` on both nodes, `set_led`, `on_organ`) |
| 1e | Wire organ sensing to activities end-to-end | **done** - as the declarative `organs` condition (not as `OrganSwapActivity`) |
| 2 | Declarative activities authored from the GUI (state-machine in DB) | **done** - see "Behaviour engine" below |

---

## Current activity system (ships today)

### `BaseActivity`

`src/activities/base_activity.py` - every activity inherits from this:

```python
class BaseActivity:
    name: str
    description: str

    def prepare_robots(self, robots): ...   # optional: wrap robots (e.g. simulate)
    def setup(self, session, robots): ...   # called by Session at start (subclasses override _setup)
    def start(self): ...
    def pause(self): ...
    def resume(self): ...
    def stop(self): ...
    def get_state(self): ...
```

### There are no code-defined activities any more

`ACTIVITIES` in `src/activities/__init__.py` is **empty**: the old hardcoded
game activities (Group Touch / Organ Swap), the standalone
`SimulationActivity`, and the auto-registered seed behaviours were all
removed. **Every activity is a declarative behaviour** authored in the block
editor and stored in the DB (`declarative_activities` table), run by
`ScriptedActivity`; example behaviours ship as importable JSON in
[`config/examples/behaviours/`](../config/examples/behaviours/). The session
dropdown is populated by `available_activities(db)` / resolved by
`get_activity(name, db)`.

Simulation is a per-activity boolean - every activity gets it for free via
`BaseActivity.simulation_mode` (the checkbox in the SessionSetupDialog).

### Where activities show up

- **SessionPanel** lets the user pick an activity + start/stop a session.
- **RobotMonitorPanel** renders `RobotMonitorWidget` per robot; each robot
  shows a `SkinWidget` per skin (with the new `SkinGridView` overlay when
  the skin has `chamber_grid` configured).
- Touch + inflate / deflate are exposed via `ChamberWidget` inside each
  `SkinWidget`.

---

## Behaviour engine (shipped) - declarative specs + block editor

The declarative behaviour engine from Phase 2 is implemented and runs the
hospital study's behaviours. Two layers:

- **Runtime:** [`ScriptedActivity`](../src/activities/scripted_activity.py)
  interprets a behaviour *spec* (plain JSON data) as a per-skin state machine
  with a cooperative sequence scheduler (`wait` / `wait_for_touch` suspend a
  running sequence). The verb set lives in
  [`catalog.py`](../src/activities/catalog.py) - actions (`set_led`,
  `set_led_halves`, `fade`, `touch_progress`, `zone_fill`, `sync_fill`, `beat`,
  `inflate`/`deflate`/`set_pressure`, `stop`, `log`, and the Thymio
  wheel/LED/sound verbs `thymio_drive` / `thymio_leds` / `thymio_sound`),
  control flow (`sequence`, `repeat`, `for_each_chamber`, `if_robot`, `wait`,
  `wait_for_touch`) and conditions (`elapsed_ms`, `touch_count`,
  `gesture_count`, `touch_rhythm`, `group_touch_sync`,
  `on_impact`, `on_lifted`, `organs`, `robot_is`,
  `any`/`all`/`not`, `always`). The catalogue is the single source
  of truth and also drives the editor blocks. Specs are validated by
  `validate_spec` (`wrinkle` is deprecated - accepted in saved specs as an
  alias of `deflate`).

  `touch_progress` fills an LED ring one arc per `per` touches (from `bg_color`
  to `on_color`, `segments` arcs) and optionally jumps to phase `to` once full;
  `gesture_count` is true after `min` gestures of `kind` - `touch` (any press,
  no model) or an ML class `tap` / `press` / `compressions` (needs a trained
  model for the skin type).

  `inflate`/`set_pressure`/`beat` also take an optional `power` (1-5, default 5)
  and `duty` (1-255): `power` is the friendly dial, mapped at runtime onto the
  skin type's calibrated duty range (1 = the Min power PWM from Calibrate Fill,
  5 = full) and overriding `duty` when both are set; `duty` is the raw pump PWM
  (`0` = full speed). **Caveat:** the firmware currently parses but does not
  apply a per-request `duty` on the engine path - pumps run at full duty (see
  [firmware/PROTOCOL.md](../firmware/PROTOCOL.md) and `FIXME.md`), so both
  fields have no effect on real hardware today.
  The LED verbs `set_led` / `set_led_halves` / `fade` take an optional `ring`
  (`"all"` default, or `0..2`): the multiplexed board defines **three independent
  24-LED rings** that can animate separately (Tree populates all three, one per
  branch skin; Turtle only ring 0), so a Tree activity can drive each ring on
  its own, while the direct board drives a single **68-pixel cut COB strip**
  wrapped round the Thymio skin (plus one empty seam slot, so arcs and comets
  are computed over 69 slots and stay continuous across the seam) and ignores
  higher indices. `ring` omitted / `"all"` keeps the prior whole-ring behaviour;
  the firmware sizes the selected ring itself. A multiplexed-authored behaviour
  run on a direct board degrades gracefully (only ring 0 shows).

  **Zone fills** light the pixels *above a touch sensor*. The strip's geometry
  ([`led_geometry.py`](../src/core/led_geometry.py): pixel count, seam gap,
  direction, brightness cap, and the mounting angle saved from the Test
  Actuators handle) and the touch profile's **sensor placements**
  ([`touch_profiles.py`](../src/hardware/touch_profiles.py): the magnet
  board's four corner quadrants, configurable per sensor in the Skin dialog's
  "Sensor positions" box; a future capacitive board reports its own) are both
  expressed as a *perimeter fraction* (0 = front centre, clockwise from above)
  and joined once per skin by
  [`TouchZoneMap`](../src/core/touch_zones.py): every pixel belongs to the
  nearest sensor, so a symmetric skin with corner sensors gets four equal
  quarters with no hand-kept table. The runtime keeps a per-skin
  [`LedZoneCanvas`](../src/activities/led_canvas.py) and renders every change
  as ONE `set_led_pixels` frame (up to 4 colours + a 2-bit-per-pixel hex
  mask, 34 chars for 68 pixels).
  - `zone_fill` (in a phase's `on_touch`): each qualifying press lights
    `step_pct` more of the touched zone - `fill` random / contiguous / centre
    (outward from the sensor); `kind` `touch` (every press) or `rhythmic`
    (only a press within `tolerance_ms` of `target_interval_ms` since the
    previous press in the *same* zone - the first press just starts the
    clock). `to` jumps once every zone is full. Steps round up, so N steps of
    1/N fill a zone.
  - `sync_fill` (in a phase's `do`): the lit share of the **whole** strip
    equals completed rounds / rounds required of the phase's
    `group_touch_sync` condition, refreshed every tick; when the streak
    breaks the pixels go out one per `decay_ms` (0 = at once).
  - `group_touch_sync` gained `mode`: `auto` (editor default) takes whoever
    presses - the first `participants` distinct sensors form the group and any
    further sensor that presses joins for good, so a fourth child may come in
    and from then on all four must keep every round (the streak restarts when
    the group grows); `fixed` (or any spec listing `sensors`) keeps the exact
    sensor list. Skins without a strip geometry or touch board make both fill
    verbs logged no-ops.
  The `organs` condition compares how many of the skin's plugged organs resolve
  to good/bad (decomposed from the organ circuit by `OrganResolver`): `scope`
  `all_good`/`all_bad` mean "every organ matches", `count` compares the good and
  bad counts via their operators (e.g. `good >= 3 and bad <= 0` to cure).

  A spec may declare a **target** with a **robot kind** and/or a **skin
  condition**: `{"kind": "thymio" | "turtle" | "tree", "skin": "natural" |
  "wrinkles" | "organs"}` (see [`activity_kind.py`](../src/activities/activity_kind.py)
  and [`skin_condition.py`](../src/activities/skin_condition.py)). The kind
  narrows the behaviour to one robot topology (the study runs Turtle
  activities and Thymio activities, never mixed); the skin says which silicone
  set it is written for, so the session setup pre-selects the matching
  activity and warns when a chosen robot's configured skin variants don't
  match. Either part may be left out ("any"); robot-specific parts of an
  any-robot behaviour are gated with `if_robot` blocks (or `robot_is`
  transition conditions).

  A phase may be flagged `"final": true` - the terminal phase of the story
  (the cured robot). The runtime reads it through `catalog.is_final_state`
  (the legacy names `complete` / `success` / `done` still count) for the live
  CPR status.

- **Authoring:** **Tools -> Activity Editor...**
  ([`activity_editor_dialog.py`](../src/gui/activity_editor_dialog.py)) is a
  thin frame around the editor panel
  ([`behavior_editor_panel.py`](../src/gui/behavior_editor_panel.py)), a
  Scratch-like **block editor** (Blockly in a `QWebEngineView`,
  [`editor.html`](../src/gui/blockly/editor.html)).

  **The blocks are generated from the catalogue.** On load the panel hands
  the page `catalog.editor_catalog()` (every verb with its `template` - the
  block's rows and words with `{field}` slots - its fields' types, choice
  labels, ranges and `show_when` rules - plus the colour palette) through
  `initEditor(payload)`. The page builds one block per verb (and per
  `Variant`, e.g. "set LED quarters"), the toolbox from `CATEGORIES`, and the
  compile / decompile code from the field list, so **adding a verb is one
  catalogue entry** - the page only changes for a new field *type*. Only the
  three structural blocks are hand-written: the behaviour root (target robot
  + skin), the phase (name, `final` checkbox, `do` / `on touch` /
  `transitions`) and the transition. Field types: numbers with bounds, times
  as a number **plus a unit** (ms / s / min, stored as ms), colours as a
  **swatch** (study palette + custom picker, no more pasting `#tags`),
  `phase` fields as a **dropdown of the phases in the workspace** (renaming a
  phase rewrites every reference), and conditional rows that appear only when
  another field calls for them (beat's soft-chamber row, the rhythm row of
  zone fill, fixed sensors of group sync).

  Save compiles the blocks to a spec, validates it (`validate_spec`, hard
  errors) and **lints** it (`lint_spec` + the page's `getWarnings()`:
  unreachable phases, fill jumps to a missing phase, a final phase with
  transitions, an `always` transition shadowing later ones, a `repeat
  forever` with nothing that takes time, duplicate phase names, loose
  blocks) - warnings can be overridden with "Save anyway". Specs are stored
  in the `declarative_activities` table; the exact workspace is stashed under
  the spec's ignored `_blockly` key (`{"format": 2, "workspace": ...}`) so
  block positions round-trip. On load the saved workspace must compile back to
  the saved spec, otherwise - and for a spec **without** a blob (hand-authored,
  imported from `config/examples/behaviours/`, or saved by the older editor) -
  the blocks are **rebuilt from the spec itself**, so nothing opens blank or
  stale. **Blockly / QtWebEngine load only inside the editor** - never during
  a session. Blockly is loaded from a vendored copy (`scripts/fetch_blockly.sh`)
  or the CDN as a fallback. (The former **Presets** tab is gone - behaviours
  authored here *are* the activities.)

  The page's JavaScript is tested without Qt: `tests/test_editor_js.py`
  drives `editor.html` in a headless Chromium through
  [`tests/editor_harness.py`](../tests/editor_harness.py) (round-trips of
  every example behaviour, phase renames, unit conversion, legacy-blob
  fallback); it skips when no Chromium/Chrome is found (`SOFTEDIBO_CHROME`
  points at one).

Saved behaviours appear in the session activity dropdown via
[`available_activities(db)` / `get_activity(name, db)`](../src/activities/__init__.py).
The study's three seed conditions (Heartbeat / Movement / Texture - behaviours
1-3 / 4-6 / 7-9, each a 3-phase timeline advancing on time **or** enough
touches) are **no longer auto-registered**: they are kept as reference specs
in [`seed_behaviors.py`](../src/activities/seed_behaviors.py) (also test
fixtures), and the importable JSON examples in
[`config/examples/behaviours/`](../config/examples/behaviours/) are the ones
to load. Representation notes: half-and-half LED is painted per-pixel in
software (`set_led_halves`); a "wrinkle" look pulls a vacuum (timed deflate,
open-loop). Editor and runtime are both exercisable in simulation.

---

## Original plan: behavior framework (historical)

> **Superseded.** The "Python plugin + DB preset" hybrid below was built
> (Phases 1b/1c) and then dropped: the declarative behaviour engine proved
> expressive enough, so the hardcoded Python activities and the preset GUI
> were removed. Kept for design rationale; the organ/LED firmware parts
> shipped as designed.

### Design choices (decided in the planning round)

| Decision | Choice | Rationale |
|---|---|---|
| Behavior format | **Hybrid: Python plugin + DB preset** | Python class hard-codes the state machine; the preset holds only tunable params (colors, timings, thresholds). Lets engineers add new activities by writing code, while educators tune existing ones in the GUI. |
| Organ sensing | Extension of `node_direct` and `node_multiplexed` | Reuses spare ADCs on existing boards - no new firmware target. |
| LED hardware (WS2818) | Same nodes (`node_direct` / `node_multiplexed`) | Same boards drive valves + lights + organ sensors. |
| Scope rollout | Incremental phases (1a -> 1e) | Each phase ships standalone value. |

### State-machine pattern (per activity)

Each activity defines, in code, a **finite state machine**:

```mermaid
stateDiagram-v2
    sick --> cured: all_organs_match

    note left of sick
        on_periodic:
        - pulse red LED
        - react to touch
    end note

    note right of cured
        on_periodic:
        - breathe (slow inflate/deflate)
        - steady green LED
    end note
```

Each state has up to three lifecycle hooks:

- `on_enter(activity)` - runs once when the state becomes active.
- `on_periodic(activity, dt_ms)` - runs at the activity's tick rate.
- `on_exit(activity)` - runs once before transitioning out.

Transitions are guarded by **conditions** evaluated each tick (or in
response to an event):

- `all_organs_match`, `touch_count >= N`, `timer >= T`, etc.

### Tunable parameters

Each Python activity declares its tunable params as a class attribute:

```python
class OrganSwapActivity(BaseActivity):
    PARAMS = [
        Param("sick_color",        "color", default="#ff0000"),
        Param("sick_pulse_ms",     "int",   default=1000, min=100, max=5000),
        Param("cured_color",       "color", default="#00ff00"),
        Param("breathe_period_ms", "int",   default=4000, min=500, max=10000),
        Param("breathe_depth_pct", "int",   default=60,   min=10,  max=100),
        Param("organ_resistance_map", "json",
              default={"liver_good": 1500, "heart_good": 2200, "lung_good": 3300}),
    ]
```

The GUI auto-generates a form from `PARAMS` (sliders, colour pickers, JSON
editor). Saved configurations live in the DB as **presets**, each with a
human-readable name. Multiple presets per activity are supported (so the
same Organ Swap can have a "1st grade easy", "2nd grade harder", etc.).

### DB schema (planned)

```
activity_presets
  preset_id TEXT PRIMARY KEY        -- "AP001", "AP002", ...
  activity_name TEXT NOT NULL       -- references ACTIVITIES registry
  name TEXT NOT NULL                -- "Easy", "Therapy v3", ...
  description TEXT
  params TEXT NOT NULL              -- JSON-encoded {param_name: value}
  created_at TEXT NOT NULL
  updated_at TEXT NOT NULL
```

### Worked example: Organ Swap

**Hardware setup (assumed)**:

- 1 silicone organ skin per robot, with 1 or 3 organ "slots". A pluggable
  organ is a silicone block with an internal resistor of a known value.
- All organ slots of the robot are wired **in parallel into ONE ADC pin**
  (we have limited GPIOs - one reading per robot/node, not per slot).
- The firmware measures the total resistance (via voltage divider) and
  broadcasts a single value per node. The PC decomposes that value via
  `1/Rtot = sum 1/Ri` against a known organ catalogue to figure out which
  organs are currently plugged in.
- Whether the per-organ identity is reported, or only an aggregate "all
  organs are good" flag, is a configuration choice on the PC side (see
  `organ_readout_mode` below) - both modes work off the same firmware
  payload, so we don't have to commit to one shape today.

**Activity flow**:

1. State `sick` (default):
   - LED: red, pulses at `sick_pulse_ms`.
   - Robot reacts to touch: each press inflates the corresponding chamber
     briefly.
2. Transition condition: `all_organs_match` - every organ slot reads the
   resistance configured for the "good" organ in `organ_resistance_map`.
3. State `cured`:
   - LED: solid green.
   - Robot starts breathing: slow inflate/deflate cycle at
     `breathe_period_ms` with amplitude `breathe_depth_pct`.

All values above are editable in the GUI via the preset form.

---

## Firmware extensions (Phase 1d - shipped)

See [firmware/PROTOCOL.md](../firmware/PROTOCOL.md) for the wire format as
implemented (`organ.h` on both nodes; the multiplexed node adds a per-slot
`slot` field, and LED verbs gained `ring` / `fade_ms`).

### Organ sensing

Both `node_direct` and `node_multiplexed` gain a single organ ADC input
(one pin per board variant, configurable at compile time). All organ slots
on that robot are wired in parallel into this pin.

The firmware:

- Samples the pin periodically (>= 10 Hz; cheap relative to chamber sampling).
- Converts ADC reading -> resistance via voltage-divider math:
  `R_total = R_known * V_out / (V_in - V_out)`.
- Broadcasts `{"type":"organ", "resistance_ohm":R}` whenever the value
  changes by more than a hysteresis threshold (no spam on noise; no
  per-slot info because there is none in the hardware).

**Parallel decomposition** runs on the **PC side**. The activity preset
holds a catalogue `{organ_id: resistance_ohm}`; for the measured total,
the PC enumerates plausible combinations and picks the one whose
parallel-equivalent resistance matches within tolerance.

Optionally the activity can ignore the decomposition entirely and just
check the total resistance against a "cured" target - useful when we only
need to know *all good* vs *not all good*, not which organ is missing.
The choice is exposed as a preset parameter (`organ_readout_mode`:
`per_organ` or `aggregate`).

### WS2818 LED control (historical)

> **Historical.** The shipped LEDs are WS2812/SK6812 rings, and the firmware
> patterns are `off` / `solid` / `blink` / `pulse` / `comet` / `fade` (plus
> `set_led_halves`) - there is no `breathe` or `rainbow`. The current wire
> format is in [firmware/PROTOCOL.md](../firmware/PROTOCOL.md).

The original plan had both firmwares accept:

| `cmd` | Fields | Notes |
|---|---|---|
| `set_led` | `color` (`"#RRGGBB"`), `pattern` (`solid`/`pulse`/`breathe`/`rainbow`/`off`), `period_ms`, `count` (LEDs to light, default all) | Drives the WS2818 strip attached to the node. |

The pattern animations run inside the firmware loop - the PC just sets
intent. Saves ESP-NOW bandwidth and keeps animations smooth even if WiFi is
flaky.

### New Python wrappers (`ESP32Controller`)

- `set_led(color, pattern, period_ms=1000, count=None, ...) -> bool`
- `on_organ(callback) -> None`  # callback signature: `(resistance_ohm: float, slot: int)`

The `_handle_message` dispatcher routes `type=="organ"` messages to the
registered callbacks. The direct node has one organ circuit (slot 0); the
multiplexed node reads one circuit per configured `organ_channels` mux channel
and reports its `slot`. Per-organ decomposition of a circuit's parallel
resistance lives on the PC side (`OrganResolver` / the organ catalogue).

---

## GUI extensions (Phase 1b - shipped)

### Simulation mode is a per-activity checkbox

The activity dropdown in `SessionSetupDialog` no longer lists "Simulation"
as a separate activity. Instead, a `QCheckBox` labelled
**"Run in simulation mode (no real hardware)"** sits right below it. When
ticked, the chosen activity runs against `SimulatedRobot` instances backed
by `SimulatedController` - same monitor widgets, same flows, no ESP-NOW
traffic. Reads via `SessionSetupDialog.simulation_mode`; written to
`activity.simulation_mode` by `SessionPanel` before `prepare_robots` runs.

### Built-in `SIM_PARAMS`

Every activity inherits a baseline set of simulation knobs declared on
`BaseActivity.SIM_PARAMS`:

| Param | Type | Default | What it controls |
|---|---|---|---|
| `sim_inflate_speed_pct_per_s` | int | 33  | Simulated chamber fill rate |
| `sim_deflate_speed_pct_per_s` | int | 33  | Simulated chamber drain rate |
| `sim_touch_release_delay_ms`  | int | 300 | Delay after touch release before deflate ramp |

`BaseActivity.all_params()` returns `SIM_PARAMS + PARAMS` so the preset
editor renders them at the top of every activity's form. Subclasses just
add their own activity-specific `PARAMS`; simulation knobs come for free.

The values flow:
`activity.param_values -> wrap_robots_in_simulation(sim_params) -> SimulatedRobot -> SimulatedController`,
where the controller converts the `%/s` values to per-tick step sizes on
its 100-ms internal timer.

### Preset editor (removed)

> **Removed.** The Presets tab / preset editor GUI was dropped when the
> hardcoded activities went away - block-authored behaviours replaced presets
> as "the thing you tune". The DB table + CRUD below still exist (unused by
> the GUI). Historical description follows.

Layout:

```
+---------------------------------------------------------+
| Activity:    [Group Touch v]                            |
| Preset:      [Easy [AP001] v]  [+ New] [Delete]         |
| Name:        [Easy______________________]               |
| Description: [____________________________________]     |
| -------- Parameters --------                            |
| Sim inflate speed (%/s): [33__]                         |
| Sim deflate speed (%/s): [33__]                         |
| Sim touch release (ms):  [300_]                         |
| (activity-specific params follow...)                    |
|                                                         |
|                                    [Save] [Close]       |
+---------------------------------------------------------+
```

Auto-generated form based on `activity.all_params()`:

| Param type | Widget |
|---|---|
| `int` | `QSpinBox` (respects `min` / `max`) |
| `float` | `QDoubleSpinBox` (respects `min` / `max`) |
| `bool` | `QCheckBox` |
| `color` | Coloured button -> `QColorDialog` on click |
| `enum` | `QComboBox` populated from `Param.choices` |
| `json` | `QPlainTextEdit` with JSON validation on save |
| `str` | `QLineEdit` |

Flow:

- Pick an activity -> form is rebuilt for that activity's params; preset
  dropdown reloads.
- Pick a preset -> form fills with that preset's values.
- **+ New** -> resets to defaults so the operator can author a fresh preset
  without losing the saved ones.
- **Save** - upserts the current form into the DB. Empty `Name` is
  rejected; invalid JSON in a `json` param is flagged.
- **Delete** - confirms then drops the row from the DB.
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

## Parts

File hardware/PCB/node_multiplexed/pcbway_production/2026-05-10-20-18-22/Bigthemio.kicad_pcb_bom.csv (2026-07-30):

Designator | Quantity | Value | Footprint | Package | MPN | DNP | Mount_Type | Description | MF | MAXIMUM_PACKAGE_HEIGHT | Price | Check_prices | STANDARD | PARTREV | SnapEDA_Link | MP | Description_1 | Availability | MANUFACTURER | Purchase-URL
C1, C10, C11, C12, C14, C15, C16, C19, C2, C20, C23, C3, C4, C5, C6, C7, C8, C9 | 18 | 0.1µF | C_Disc_D5.0mm_W2.5mm_P5.00mm |  |  |  | tht | Unpolarized capacitor
C13 | 1 | 10µF | CP_Radial_D5.0mm_P2.00mm |  |  |  | tht | capacitor, small US symbol
C17, C21, C22 | 3 | 100µF | CP_Radial_D5.0mm_P2.00mm |  |  |  | tht | capacitor, small US symbol
C18, C24, C25, C26 | 4 | 47µF | CP_Radial_D5.0mm_P2.00mm |  |  |  | tht | capacitor, small US symbol
C27 | 1 | 1000µF | CP_Radial_D5.0mm_P2.00mm |  |  |  | tht | capacitor, small US symbol
J1 | 1 | SWR201-NRTN-S04-SA-WH | SULLINS_SWR201-NRTN-S04-SA-WH | None |  |  | tht |  | Sullins Connector Solutions | 6.00mm | None | https://www.snapeda.com/parts/SWR201-NRTN-S04-SA-WH/Sullins/view-part/?ref=eda | Manufacturer Recommendations | A | https://www.snapeda.com/parts/SWR201-NRTN-S04-SA-WH/Sullins/view-part/?ref=snap | SWR201-NRTN-S04-SA-WH | Connector Header Through Hole 4 position 0.079 (2.00mm) | In Stock | Sullins
J10, J15, J16, J17, J18, J29, J3, J4, J44, J52, J6, J9 | 12 | B2B-XH-A | JST_B2B-XH-A | None |  |  | tht |  | JST Sales | 7 mm | None | https://www.snapeda.com/parts/B2B-XH-A/JST/view-part/?ref=eda | Manufacturer Recommendations | N/A | https://www.snapeda.com/parts/B2B-XH-A/JST/view-part/?ref=snap | B2B-XH-A | Connector Header Through Hole 2 position 0.098 (2.50mm) | In Stock | JST Sales America Inc. | https://www.snapeda.com/api/url_track_click_mouser/?unipart_id=552747&manufacturer=JST Sales&part_name=B2B-XH-A&search_term=b2b-xh-a
J11, J32, J33 | 3 | Conn_01x02_Pin | PinHeader_1x02_P2.54mm_Vertical |  |  |  | tht | Generic connector, single row, 01x02, script generated
J12, J13, J23, J24, J26, J27 | 6 | 691137710002 | 691137710002 | None |  |  | tht |  | Würth Elektronik |  | None | https://www.snapeda.com/parts/691137710002/W%25C3%25BCrth+Elektronik+Midcom/view-part/?ref=eda |  |  | https://www.snapeda.com/parts/691137710002/W%25C3%25BCrth+Elektronik+Midcom/view-part/?ref=snap | 691137710002 | 2 Position Wire to Board Terminal Block Horizontal with Board 0.197 (5.00mm) Through Hole | In Stock |  | https://www.snapeda.com/api/url_track_click_mouser/?unipart_id=4793356&manufacturer=Würth Elektronik&part_name=691137710002&search_term=691137710002
J14, J19, J2, J20, J21, J22, J28, J30, J5, J51, J53, J7 | 12 | S2B-XH-A | JST_S2B-XH-A | None |  |  | tht |  | JST Sales |  | None | https://www.snapeda.com/parts/S2B-XH-A/JST/view-part/?ref=eda |  |  | https://www.snapeda.com/parts/S2B-XH-A/JST/view-part/?ref=snap | S2B-XH-A | Connector Header Through Hole, Right Angle 2 position 0.098 (2.50mm) | In Stock | JST | https://www.snapeda.com/api/url_track_click_mouser/?unipart_id=53371&manufacturer=JST Sales&part_name=S2B-XH-A&search_term=conector s2b-xh-a
J25, J8 | 2 | Conn_01x08_Pin | PinHeader_1x08_P2.54mm_Vertical |  |  |  | tht | Generic connector, single row, 01x08, script generated
J31, J54, J58, J59, J60, J61, J62, J63, J64, J65, J66, J67, J68 | 13 | Conn_01x03_Pin | PinHeader_1x03_P2.54mm_Vertical |  |  |  | tht | Generic connector, single row, 01x03, script generated
J34, J35, J36, J37, J38, J39, J40, J41, J42, J43, J45, J46, J47, J48, J49, J50 | 16 | Conn_01x01_Pin | PinHeader_1x01_P2.54mm_Vertical |  |  |  | tht | Generic connector, single row, 01x01, script generated
R1, R2 | 2 | 4k7 | R_Axial_DIN0207_L6.3mm_D2.5mm_P7.62mm_Horizontal |  |  |  | tht | Resistor
R3 | 1 | R | R_Axial_DIN0207_L6.3mm_D2.5mm_P7.62mm_Horizontal |  |  |  | tht | Resistor
U1 | 1 | ESP32-DEVKITC-32E | MODULE_ESP32-DEVKITC-32E | None |  |  | tht |  | Espressif Systems |  | None | https://www.snapeda.com/parts/ESP32-DEVKITC-32E/Espressif+Systems/view-part/?ref=eda | Manufacturer Recommendations | 1.4 | https://www.snapeda.com/parts/ESP32-DEVKITC-32E/Espressif+Systems/view-part/?ref=snap | ESP32-DEVKITC-32E | The ESP32-DEVKITC-32E transceiver evaluation board from Espressif Systems is a powerful development tool for wireless communication technologies. It supports 802.11 b/g/n Wi-Fi and Bluetooth® Smart Ready 4.x (BLE) dual-mode at 2.4GHz, making it ideal for a variety of IoT applications. Equipped with a PCB antenna and 4MB flash, this board provides reliable connectivity and ample memory for developing and testing RF, RFID, and wireless solutions. | In Stock | Espressif Systems | https://www.snapeda.com/api/url_track_click_mouser/?unipart_id=4719025&manufacturer=Espressif Systems&part_name=ESP32-DEVKITC-32E&search_term=esp32
U10, U11, U12, U13, U14, U15, U16, U17, U18, U2, U3, U4 | 12 | ~ | XGP6847A_TiagoDias |  |  |  | tht
U19, U7, U9 | 3 | 3297 | MODULE_3297 | None |  |  | tht |  | Adafruit Industries | NA | None | https://www.snapeda.com/parts/3297/Adafruit+Industries/view-part/?ref=eda | Manufacturer Recommendations | 2020-11-20 | https://www.snapeda.com/parts/3297/Adafruit+Industries/view-part/?ref=snap | 3297 | DRV8833 - Motor Controller/Driver Power Management Evaluation Board | In Stock | Adafruit
U20, U6, U8 | 3 | ULN2803A | UNL | DIP-18 Allegro MicroSystems LLC |  |  | tht |  | STMicroelectronics | 3.93mm | None | https://www.snapeda.com/parts/ULN2803A/STMicroelectronics/view-part/?ref=eda | IPC-7351B | 4 | https://www.snapeda.com/parts/ULN2803A/STMicroelectronics/view-part/?ref=snap | ULN2803A | Bipolar (BJT) Transistor Array 8 NPN Darlington 50V 500mA - 2.25W Through Hole 18-DIP | In Stock | STMicroelectronics | https://www.snapeda.com/api/url_track_click_mouser/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
U21, U5 | 2 | PCA9685PW | TSSOP-28_4.4x9.7mm_P0.65mm |  |  |  | smt | 16-channel 12-bit PWM Fm+ I2C-bus LED controller RGBA TSSOP
U22 | 1 | CD74HC4067SM | SSOP-24_5.3x8.2mm_P0.65mm |  |  |  | smt | High-Speed CMOS Logic 16-Channel Analog Multiplexer/Demultiplexer, SSOP-24

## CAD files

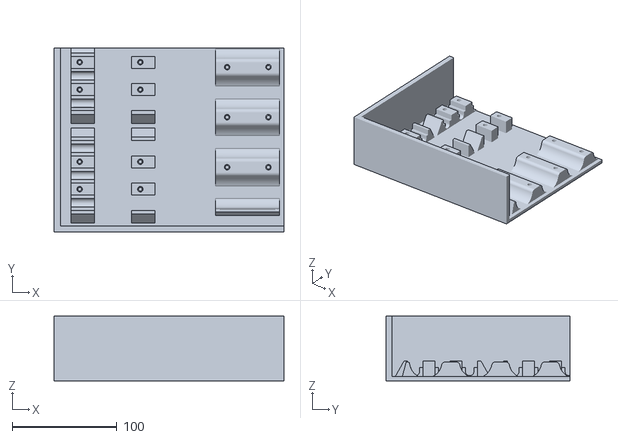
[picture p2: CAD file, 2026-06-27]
3Dmodels/Enclosures/CommonBase/STL/TotalBaseLeft.stl
220.0 x 176.4 x 62.0

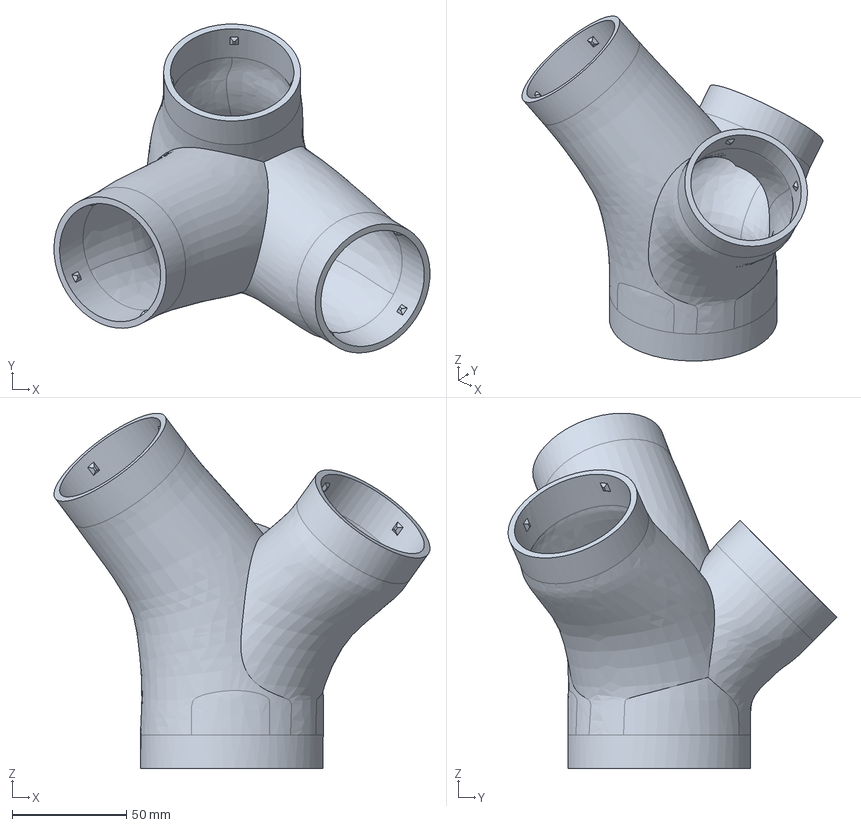
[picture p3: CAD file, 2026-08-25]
3Dmodels/Enclosures/Tree/STEP/TreeMainBranch.step
164.5 x 143.9 x 155.5 mm

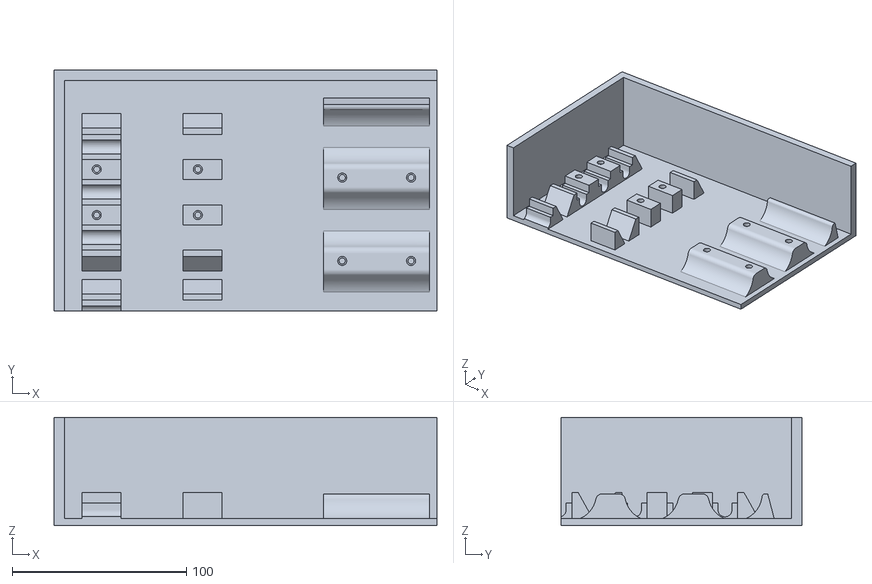
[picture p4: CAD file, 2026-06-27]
3Dmodels/Enclosures/CommonBase/STL/TotalBaseRight.stl
220.0 x 138.5 x 62.1

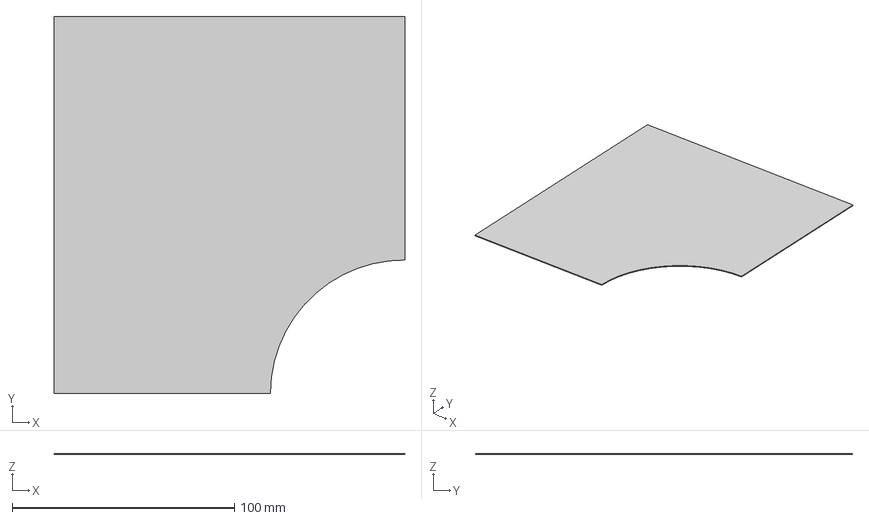
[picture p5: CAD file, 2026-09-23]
3Dmodels/Enclosures/CommonBase/STEP/SheetCoverQuarter.step
157.7 x 169.5 x 0.5 mm

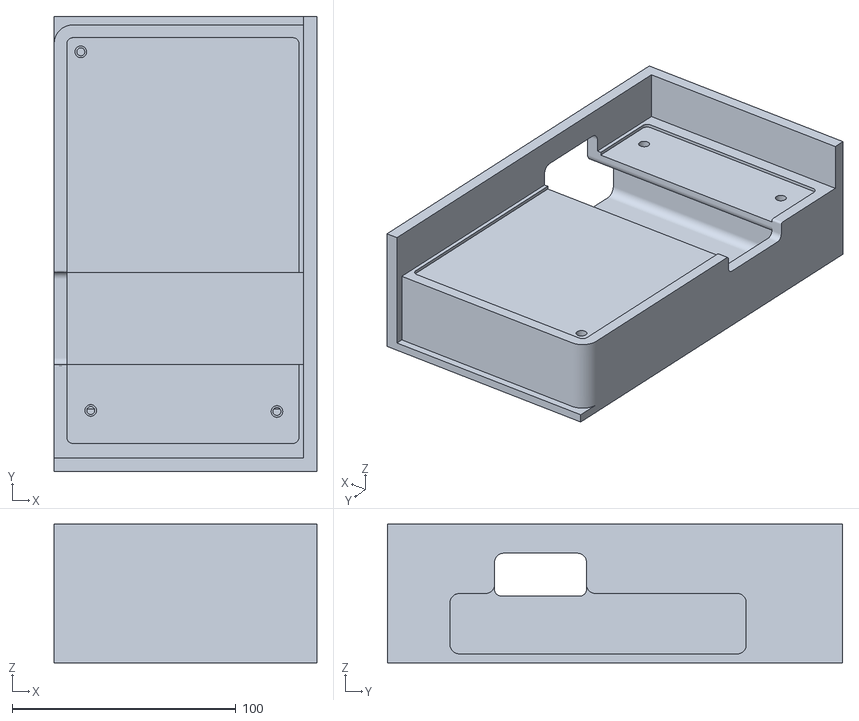
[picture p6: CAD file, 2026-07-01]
3Dmodels/Enclosures/CommonBase/STL/PowerBankHolder.stl
117.3 x 203.3 x 62.0

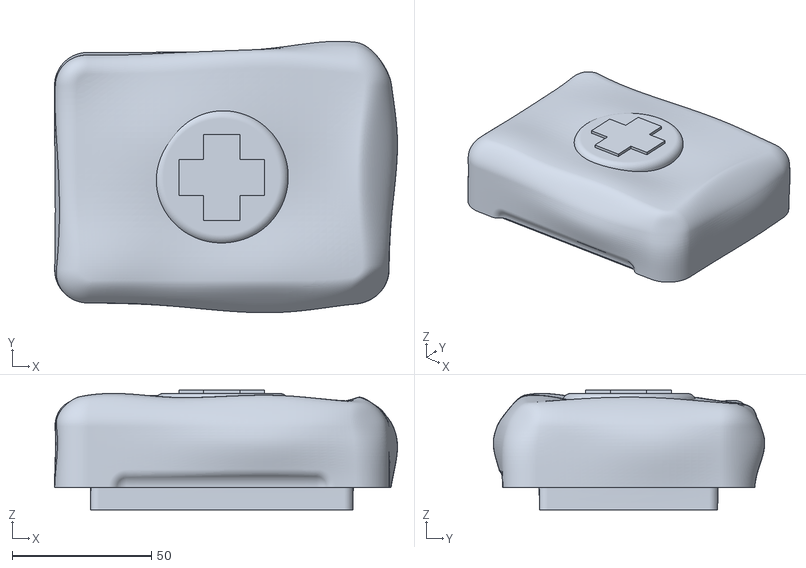
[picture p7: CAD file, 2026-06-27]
3Dmodels/Enclosures/OrganBoxes/STL/BoxLid.stl
123.0 x 97.4 x 43.0

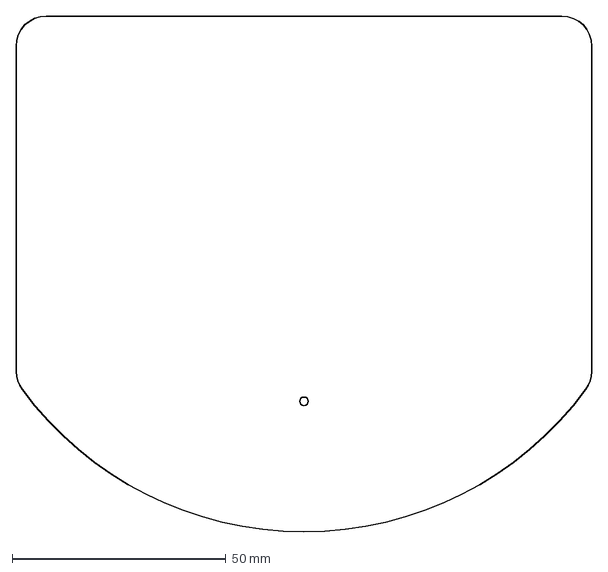
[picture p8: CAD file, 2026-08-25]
3Dmodels/Enclosures/Thymio/DXF/ThymioSkinTemplate.dxf
134.5 x 120.5 mm

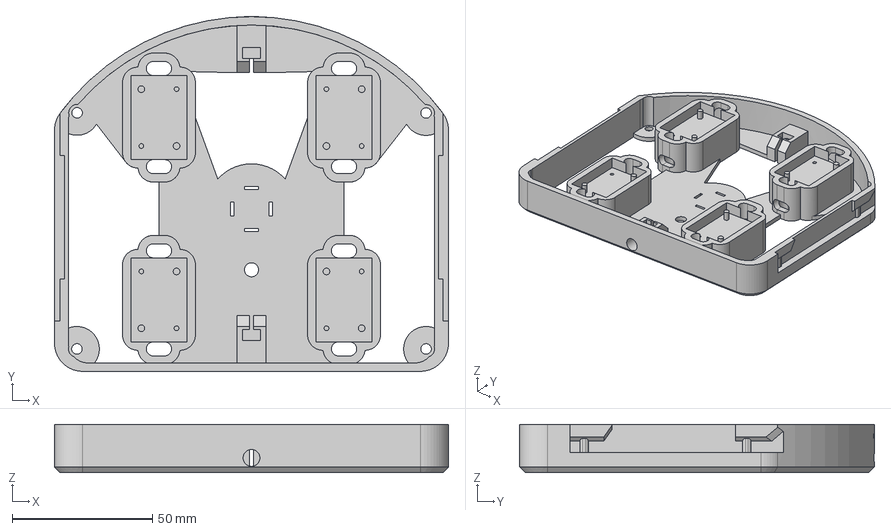
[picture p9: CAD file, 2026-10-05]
3Dmodels/Enclosures/Thymio/STEP/ThymioSkinAdapterMagnetsLEDStrip.step
140.5 x 126.5 x 17.2 mm

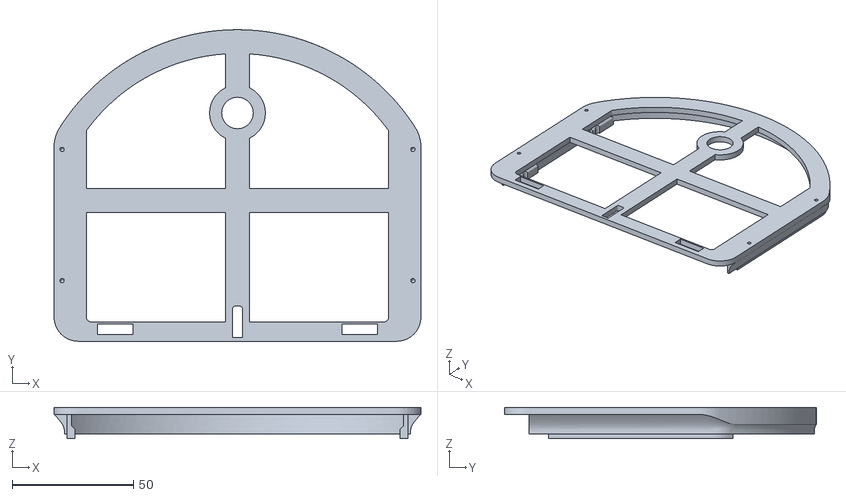
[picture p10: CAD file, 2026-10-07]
3Dmodels/Enclosures/Thymio/STL/ThymioSkinHolderNoLEDRing.stl
151.1 x 128.3 x 12.9

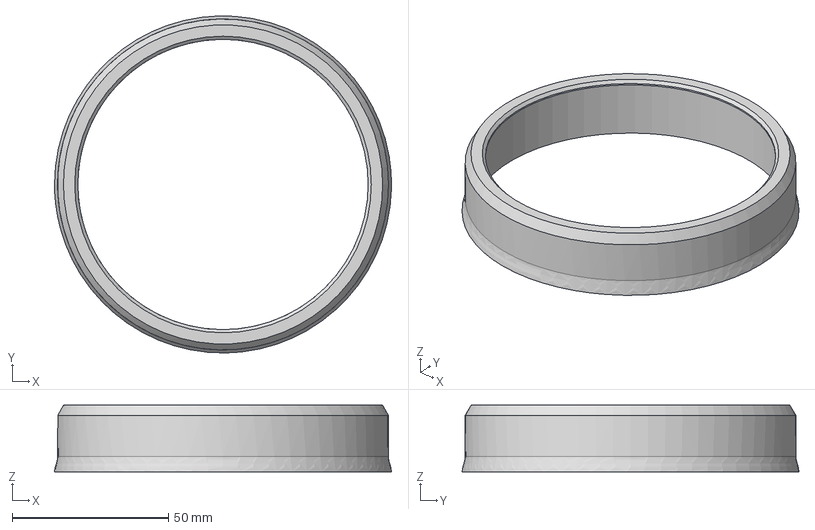
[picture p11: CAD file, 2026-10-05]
3Dmodels/Enclosures/Tree/STEP/TreeSkinCover.step
108.0 x 108.0 x 21.4 mm

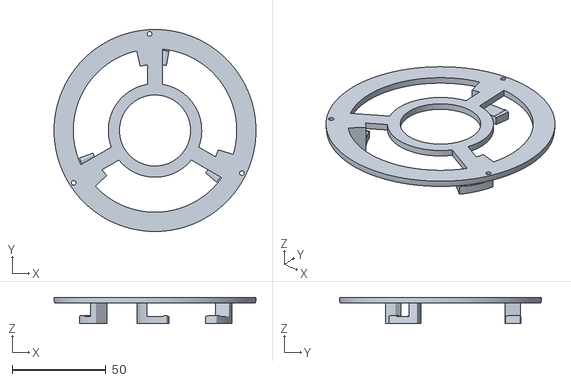
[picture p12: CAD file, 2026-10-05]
3Dmodels/Enclosures/Tree/STL/TreeSkinBase.stl
108.0 x 108.0 x 14.0

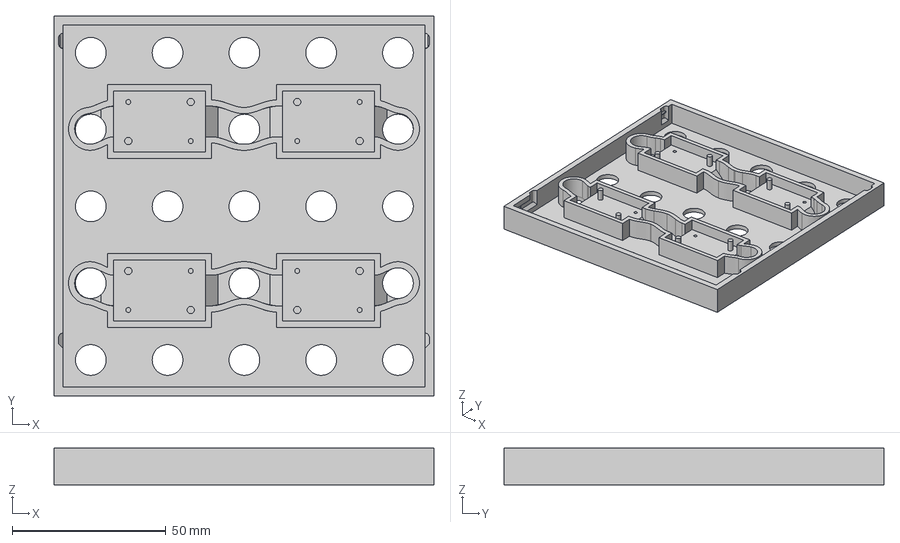
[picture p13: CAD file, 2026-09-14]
3Dmodels/Enclosures/Turtle/MagnetSensors/STEP/TurtleSquareAdapter.step
123.7 x 123.7 x 12.0 mm

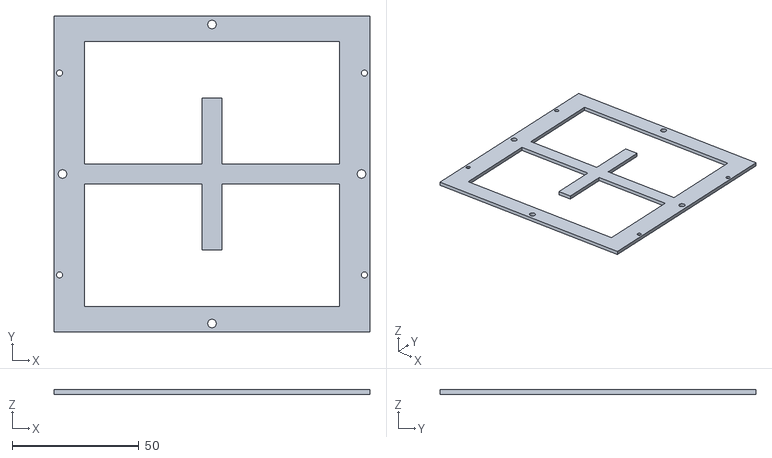
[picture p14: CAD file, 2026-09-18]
3Dmodels/Enclosures/Turtle/MagnetSensors/STL/TurtleSquareInsertsMagnetsSkinHolder.stl
124.7 x 124.7 x 2.00

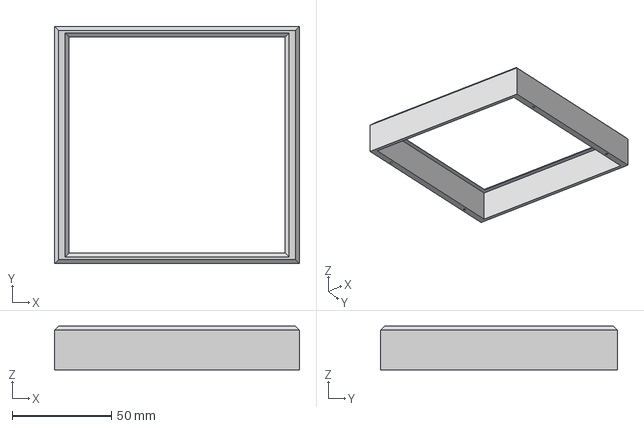
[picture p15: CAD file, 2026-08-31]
3Dmodels/Enclosures/Turtle/STEP/TurtleSquareSkinCover.step
123.7 x 119.7 x 22.0 mm

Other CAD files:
3Dmodels/Gateway/STL/GatewayCaseTop.stl
3Dmodels/SkinMolds/Shared/STL/OrganElipse.stl
3Dmodels/SkinMolds/Thymio/STL/ThymioWrinkles.stl
3Dmodels/SkinMolds/Tree/DXF/TreeTopHoles.dxf
3Dmodels/Enclosures/CommonBase/F3d/BoxFrame.f3z
3Dmodels/Enclosures/CommonBase/STEP/BoxFrameBackLeft.step
3Dmodels/Enclosures/CommonBase/STEP/BoxFrameBackRight.step
3Dmodels/Enclosures/CommonBase/STEP/BoxFrameFrontLeft.step
3Dmodels/Enclosures/CommonBase/STEP/BoxFrameFrontRight.step
3Dmodels/Enclosures/CommonBase/STEP/PowerbankLid.step
3Dmodels/Enclosures/CommonBase/STL/BoxFrameBackLeft.stl
3Dmodels/Enclosures/CommonBase/STL/BoxFrameBackRight.stl
3Dmodels/Enclosures/CommonBase/STL/BoxFrameFrontLeft.stl
3Dmodels/Enclosures/CommonBase/STL/BoxFrameFrontRight.stl
3Dmodels/Enclosures/CommonBase/STL/FittingTest-0.2.stl
3Dmodels/Enclosures/CommonBase/STL/FittingTest-0.4.stl
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

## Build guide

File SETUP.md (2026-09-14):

# Study Setup Guide

Practical setup notes for whoever builds and runs a SoftEdIBO study session.
For the application install/usage see [README.md](README.md); for the study
protocol see [docs/STUDY_PLAN.md](docs/STUDY_PLAN.md); for the touch-sensing
design see [docs/TOUCH_POSITION_TRACKING.md](docs/TOUCH_POSITION_TRACKING.md) and
[docs/TOUCH_ML.md](docs/TOUCH_ML.md).

---

## 1. Skins: shape (`skin_type`) and silicone (`skin_variant`)

Each skin is described by two independent fields in the settings file (set them
in the GUI: **Robot config -> skin -> "Skin type"** and **"Silicone"**). The app
uses the user copy, `~/.local/share/SoftEdIBO/config/settings.yaml`
(`%APPDATA%\SoftEdIBO\config\settings.yaml` on Windows), copied from the repo's
`config/settings.yaml` on first run:

- **`skin_type`** - the shape, which fixes the sensor layout and selects the
  touch-gesture model. Registered in
  [src/hardware/skin_geometry.py](src/hardware/skin_geometry.py).
- **`skin_variant`** - the silicone format (different chamber sizes per format).
  Orthogonal to the shape; fed to the touch ML as a feature. `natural` and
  `wrinkles` exist for every type; the organ-bearing variants depend on the
  type (`organ` for `tree_round`, `three_organ` for `turtle_square`,
  `organ_rectangle` / `organ_triangle` / `organ_ellipse` for `thymio` - see
  `VARIANTS_BY_TYPE` in [src/hardware/skin_geometry.py](src/hardware/skin_geometry.py)).

So e.g. a wrinkled turtle top is `skin_type: turtle_square`,
`skin_variant: wrinkles`.

---

## 2. Magnetic touch sensors per skin

The touch board (`node_magnet_sensor`) carries up to **4 MLX90393** 3-axis
magnetometers. A magnet sits above each sensor in the silicone; pressing the
skin moves the magnet closer and the reading rises. **How many sensors a skin
uses depends on the build** (what fits around the air tubes):

| skin_type | sensors | What it can resolve |
|---|:---:|---|
| `tree_round` | 1 | tap / press / hold only (magnitude + timing) |
| `turtle_side` | 2 | the above **+ one axis** of direction |
| `turtle_square`  | 4 | full quadrant **position + drag** |
| `turtle_triangle`| 4 | full position |
| `thymio` | 4 | full position |

> **Limitation (by design):** spatial quadrant position tracking only engages at
> **4 sensors** (see `Skin._setup_touch_tracking`,
> [src/hardware/skin.py](src/hardware/skin.py)). Fewer-sensor skins still get
> touch *reactions* and per-skin-type **gesture** ML, but no continuous position.

---

## 3. Magnet polarity

**Polarity is a hardware build choice, not a software setting** - there is no
polarity option in the app or firmware, and none is needed. The quadrant detector
([src/hardware/quadrant_detector.py](src/hardware/quadrant_detector.py), a port of
the thesis detector) decides which sensor/quadrant is touched purely from each
sensor's **magnitude** (uT): per-sensor threshold + hysteresis, dominant quadrant
= the strongest sensor. **It never uses the magnet's polarity (sign).**

**Is alternating polarity better?** Yes - marginally, and never worse, on
4-sensor skins. A neighbouring magnet of *opposite* polarity *subtracts* from a
sensor's own-magnet field instead of adding to it, so pressing one quadrant is
less likely to spuriously raise an adjacent sensor -> cleaner thresholds, better
multi-touch separation, less flicker at boundaries. (In SoftEdIBO each magnet
sits directly above its own well-separated sensor, so cross-talk is already low -
hence "better", not "required".)

**Decision for this project: magnets are NOT alternated** (all same polarity) -
the gain is small in this layout and not worth the build complexity. Alternating
`+ - / - +` on 4-sensor skins would only buy slightly cleaner multi-touch
boundaries, and what it buys is recoverable in software anyway (below).

**If you don't alternate, what you lose and how to recover it:**

- You lose a little cross-talk margin between adjacent quadrants on **4-sensor**
  skins only (fuzzier boundaries / multi-touch). Detecting *which single*
  quadrant still works - the own-magnet dominates each sensor by distance.
- Nothing is lost for gesture ML (uses magnitude/timing, polarity-agnostic) or
  for 1-2 sensor skins.
- **Recover it for free:** (1) **Re-zero** subtracts the static cross-talk (it
  re-baselines the sensors, so resting readings settle near 0); (2) tune
  **per-sensor thresholds + hysteresis** in the Touch Tuning panel (section 4) above
  the residual. This handles the normal case.
- **Optional, for maximum separation:** a cross-talk "unmixing" calibration -
  press each quadrant alone, record the 4x4 response, invert it to separate the
  quadrants regardless of polarity (the linear/KNN idea from the thesis). Not
  implemented; add it only if dense 4-sensor multi-touch ever needs it.

> Polarity is never a software setting either way; if you ever wanted the
> software to *exploit* the sign, that would need a firmware change to stream a
> signed axis instead of magnitude - not necessary (the thesis validated the
> magnitude approach).

---

## 4. Calibrating touch thresholds

Touch detection uses **absolute magnitude thresholds (uT)**, so each build needs
a quick threshold tune (no ML, no dataset):

1. Open the monitor for the skin (4-sensor skins show the **Touch Tuning** panel).
2. **Re-zero** at rest so resting readings settle near 0.
3. Press each quadrant and note the peak; set each per-sensor threshold **above**
   the resting noise and **below** the touched peak (default 100 uT is
   conservative). Add hysteresis to stop flickering at the boundary.

---

## 5. Recording & training touch gestures

1. During a session, enable recording - the stream is saved to a `.jsonl` under
   the recordings folder, **tagged with each skin's `skin_type` and
   `skin_variant`** in its header (no manual tagging needed later).
2. **Tools -> Touch Gestures**: *Add recording...* (skin type is read from the
   recording), label each touch (auto-filled from the live tags tapped during the
   session), optionally **Group** multi-touch gestures (e.g. a triple tap), then
   **Train**. One model is trained per `skin_type`; the silicone variant is used
   as a feature. See [docs/TOUCH_ML.md](docs/TOUCH_ML.md).

---

## 6. Chamber fill calibration

Chambers are **targeted by pressure**: the firmware's coupled-fill engine opens
the co-active chambers together and closes each one the moment its gauge reaches
the target (see [docs/COUPLED_FILL_CONTROL.md](docs/COUPLED_FILL_CONTROL.md) and
[docs/PRESSURE_AND_FILL_SAFETY.md](docs/PRESSURE_AND_FILL_SAFETY.md)). The
calibration curves do not replace that loop - they give each request a
**time budget** (`ms`, the engine's per-chamber open-time cap), which is the
closing authority only where the gauge cannot see (a deflate below the sensor
floor, e.g. wrinkles) and a safety bound everywhere else.

**Tools -> Calibrate Fill Times...** (or **Configure Skin -> Calibrate Fill**,
scoped to one skin) measures, per chamber:

- **Calibrate all** - the **time->pressure fill curve**: each chamber sweeps from
  empty in one continuous pass while the node streams pressure at a fast cadence
  (**Detail**). Saved as the chamber's `fill_profile`; also ranks which chamber
  fills first. An inflate's `ms` is interpolated from it and scaled by the
  node's concurrent load, `x max(1, active_chambers / pumps)`.
- **Duty curves** - fill speed at several pump PWM duties, so the activity
  editor's "over (ms)" slow-fill can pick a duty from measured data (note: the
  firmware engine path does not apply a requested `duty` yet - see FIXME.md).
  **Min power PWM** sets the duty that power level 1 maps to (level 5 = 255;
  diaphragm pumps stall below ~180).
- **Deflate curves** - the falling vacuum curve down to the sensor floor, which
  times the deflates the gauge cannot supervise.
- **Hold/leak curves** - the pump PWM that balances each chamber's leak at
  several levels (hold curve) plus the natural pressure decay (leak curve).
  Needs pressure sensors on the node.

Run it once per build / after silicone changes, with the gateway connected,
outside a running session and with hands clear; then **Save** (or **Apply** to
keep the dialog open). **Save as skin-type template** stores the curves under
`fill_profiles_by_type` (keyed by `skin_type` + `skin_variant`), so every skin of
that type inherits them unless it has its own override. Between sweeps the
chambers vent to ambient with the firmware `vent` command (both valves open,
pumps off).

> Continuous calibration currently needs the direct board (`test_run` /
> `status_rate` are not ported to the multiplexed board yet), so Calibrate Fill
> is disabled for `node_multiplexed` chambers.

**Leak compensation** is the `hold_duty` regulated hold: after every
inflate/deflate settles at a positive level, the app automatically asks the
node to hold it there - the inflate valve reopens whenever the gauge droops
below the level and the shared pump is servoed (never below 180 PWM), seeded
from the hold curve. Any new actuation on the chamber drops the hold first.
Vacuum poses (wrinkles) and sensorless boards are not auto-held.

Safety always applies regardless of calibration: a 5 s per-chamber open cap
(when no `ms` is sent), per-round / per-sequence caps, a 10 s actuation watchdog,
and the per-chamber `max_pressure` clamp.

When you start a session on real hardware, if any selected chamber has no
calibrated fill curve you're prompted to **calibrate now** (or start anyway with
plain pressure targeting and the 5 s cap). Calibrating there rebuilds the robots
so the new curves take effect - just start the session again.

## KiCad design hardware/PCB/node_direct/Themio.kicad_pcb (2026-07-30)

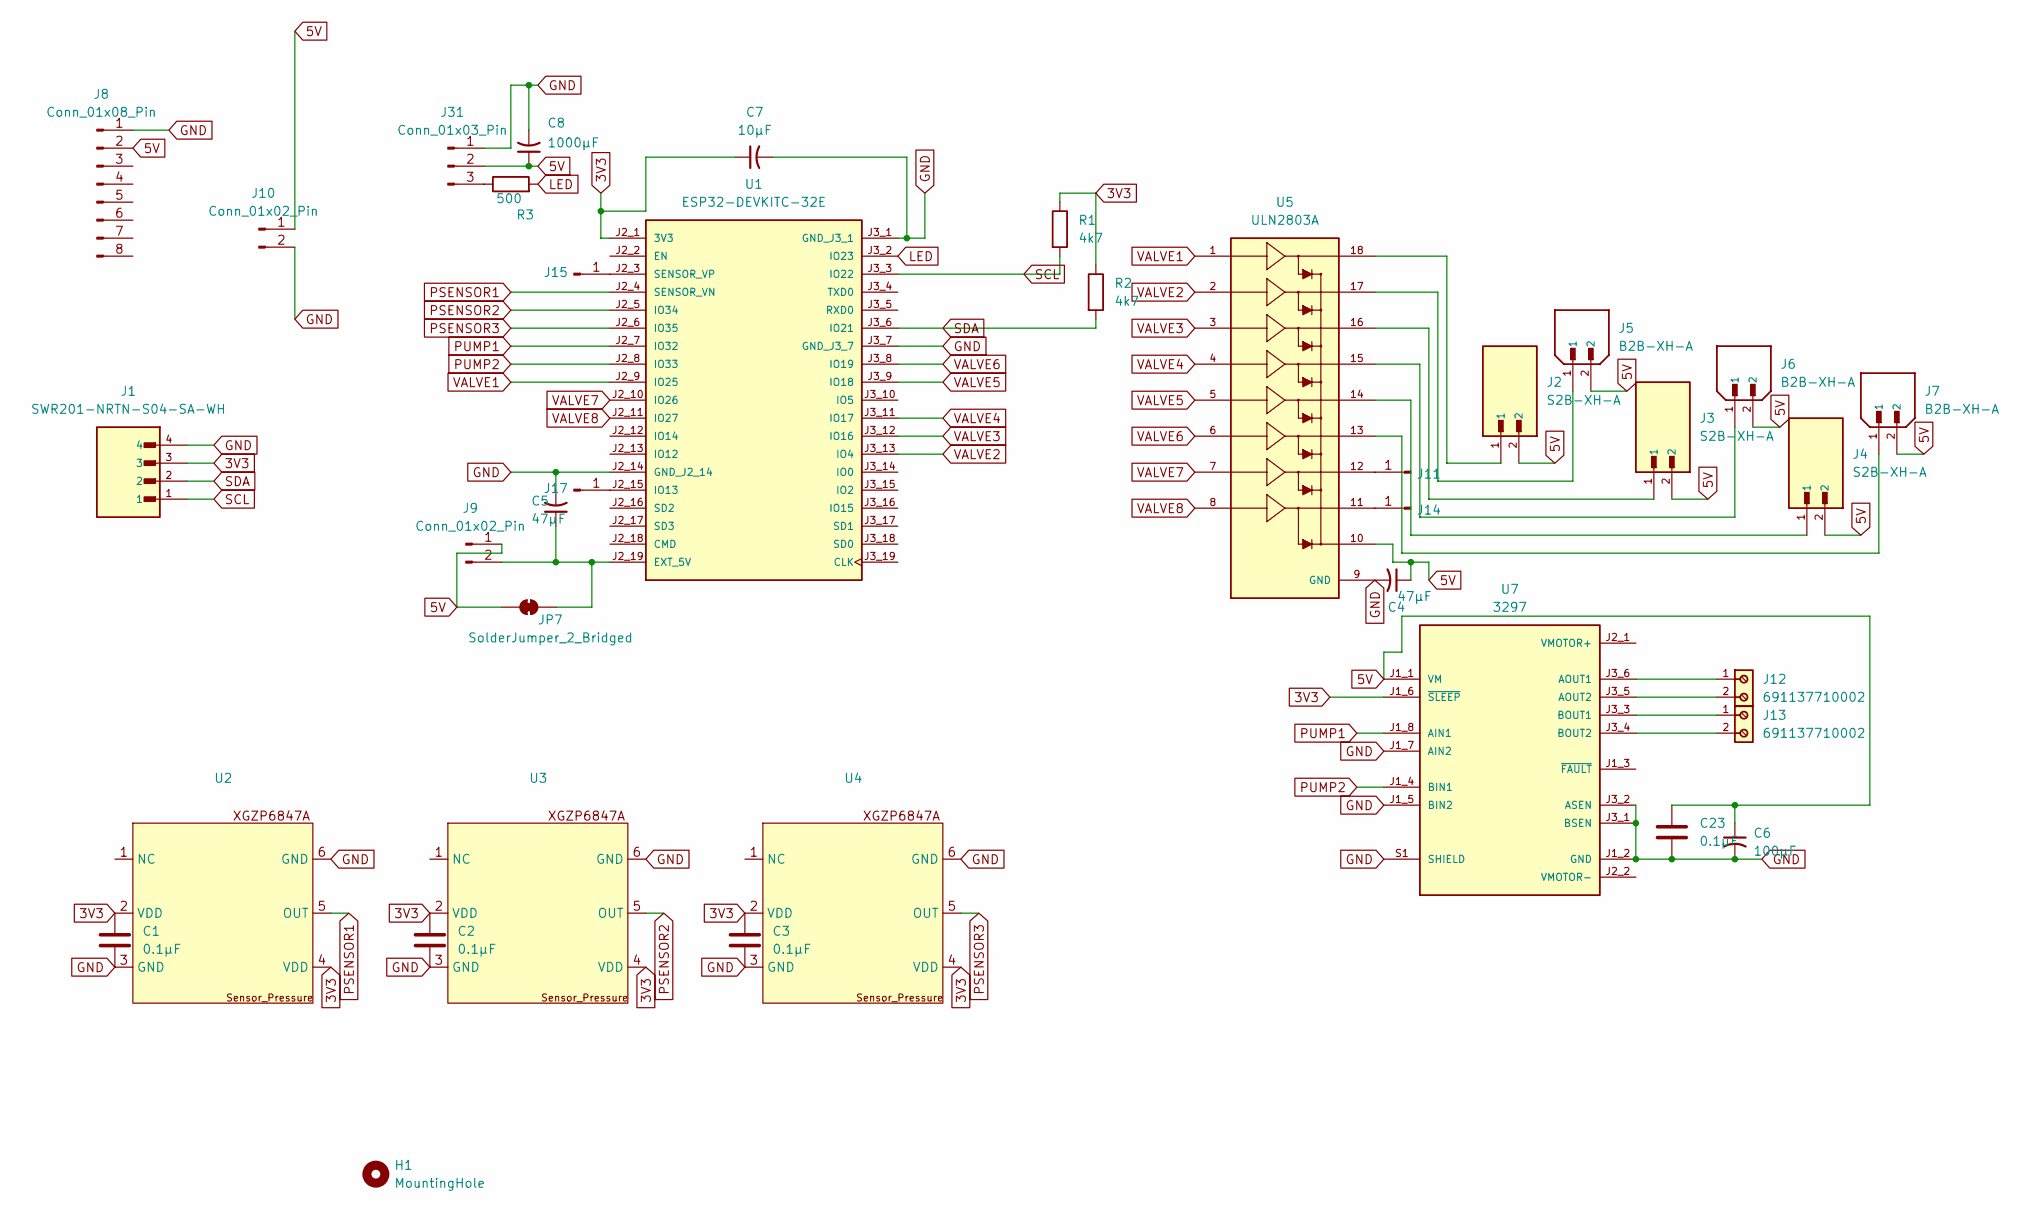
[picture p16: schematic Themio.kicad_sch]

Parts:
C1, C2, C3, C23: 0.1µF; C_Disc_D5.0mm_W2.5mm_P5.00mm
C4, C5: 47µF; CP_Radial_D5.0mm_P2.00mm
C6: 100µF; CP_Radial_D5.0mm_P2.00mm
C7: 10µF; CP_Radial_D5.0mm_P2.00mm
C8: 1000µF; CP_Radial_D5.0mm_P2.00mm
H1: MountingHole; MountingHole_4.3mm_M4
J1: SWR201-NRTN-S04-SA-WH; SULLINS_SWR201-NRTN-S04-SA-WH; PARTREV A
J2, J3, J4: S2B-XH-A; JST_S2B-XH-A
J5, J6, J7: B2B-XH-A; JST_B2B-XH-A; PARTREV N/A
J8: Conn_01x08_Pin; PinHeader_1x08_P2.54mm_Vertical
J9, J10: Conn_01x02_Pin; PinHeader_1x02_P2.54mm_Vertical
J11, J14, J15, J17: Conn_01x01_Pin; PinHeader_1x01_P2.54mm_Vertical
J12, J13: 691137710002
J31: Conn_01x03_Pin; PinHeader_1x03_P2.54mm_Vertical
JP7: SolderJumper_2_Bridged; SolderJumper-2_P1.3mm_Bridged_RoundedPad1.0x1.5mm
R1, R2: 4k7; R_Axial_DIN0207_L6.3mm_D2.5mm_P7.62mm_Horizontal
R3: 500; R_Axial_DIN0207_L6.3mm_D2.5mm_P7.62mm_Horizontal
U1: ESP32-DEVKITC-32E; MODULE_ESP32-DEVKITC-32E; PARTREV 1.4
U2, U3, U4: XGP6847A_TiagoDias
U5: ULN2803A; UNL; PARTREV 4
U7: 3297; MODULE_3297; PARTREV 2020-11-20

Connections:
3V3: C1.1, C2.1, C3.1, C7.1, J1.3, R1.1, R2.1, U1.J2_1 (3V3), U2.2 (VDD), U2.4 (VDD), U3.2 (VDD), U3.4 (VDD), U4.2 (VDD), U4.4 (VDD), U7.J1_6 (~SLEEP)
5V: C4.1, C6.1, C8.1, C23.1, J2.2, J3.2, J4.2, J5.2, J6.2, J7.2, J8.2, J9.1, J10.1, J31.2, JP7.1 (A), U5.10, U7.J1_1 (VM)
GND: C1.2, C2.2, C3.2, C4.2, C5.2, C6.2, C7.2, C8.2, C23.2, J1.4, J8.1, J10.2, J31.1, U1.J2_14 (GND_J2_14), U1.J3_1 (GND_J3_1), U1.J3_7 (GND_J3_7), U2.3 (GND), U2.6 (GND), U3.3 (GND), U3.6 (GND), U4.3 (GND), U4.6 (GND), U5.9 (GND), U7.J1_2 (GND), U7.J1_5 (BIN2), U7.J1_7 (AIN2), U7.J3_1 (BSEN), U7.J3_2 (ASEN), U7.S1 (SHIELD), U7.S2 (SHIELD)
LED: R3.2, U1.J3_2 (IO23)
unnamed: J2.1, U5.18
unnamed: J3.1, U5.16
unnamed: J4.1, U5.14
unnamed: J5.1, U5.17
unnamed: J6.1, U5.15
unnamed: J7.1, U5.13
unnamed: C5.1, J9.2, JP7.2 (B), U1.J2_19 (EXT_5V)
unnamed: J11.1, U5.12
unnamed: J14.1, U5.11
unnamed: J15.1, U1.J2_3 (SENSOR_VP)
unnamed: J17.1, U1.J2_15 (IO13)
unnamed: J31.3, R3.1
unnamed: J12.1, U7.J3_6 (AOUT1)
unnamed: J12.2, U7.J3_5 (AOUT2)
unnamed: J13.1, U7.J3_3 (BOUT1)
unnamed: J13.2, U7.J3_4 (BOUT2)
PSENSOR1: U1.J2_4 (SENSOR_VN), U2.5 (OUT)
PSENSOR2: U1.J2_5 (IO34), U3.5 (OUT)
PSENSOR3: U1.J2_6 (IO35), U4.5 (OUT)
PUMP1: U1.J2_7 (IO32), U7.J1_8 (AIN1)
PUMP2: U1.J2_8 (IO33), U7.J1_4 (BIN1)
SCL: J1.1, R1.2, U1.J3_3 (IO22)
SDA: J1.2, R2.2, U1.J3_6 (IO21)
VALVE1: U1.J2_9 (IO25), U5.1
VALVE2: U1.J3_13 (IO4), U5.2
VALVE3: U1.J3_12 (IO16), U5.3
VALVE4: U1.J3_11 (IO17), U5.4
VALVE5: U1.J3_9 (IO18), U5.5
VALVE6: U1.J3_8 (IO19), U5.6
VALVE7: U1.J2_10 (IO26), U5.7
VALVE8: U1.J2_11 (IO27), U5.8

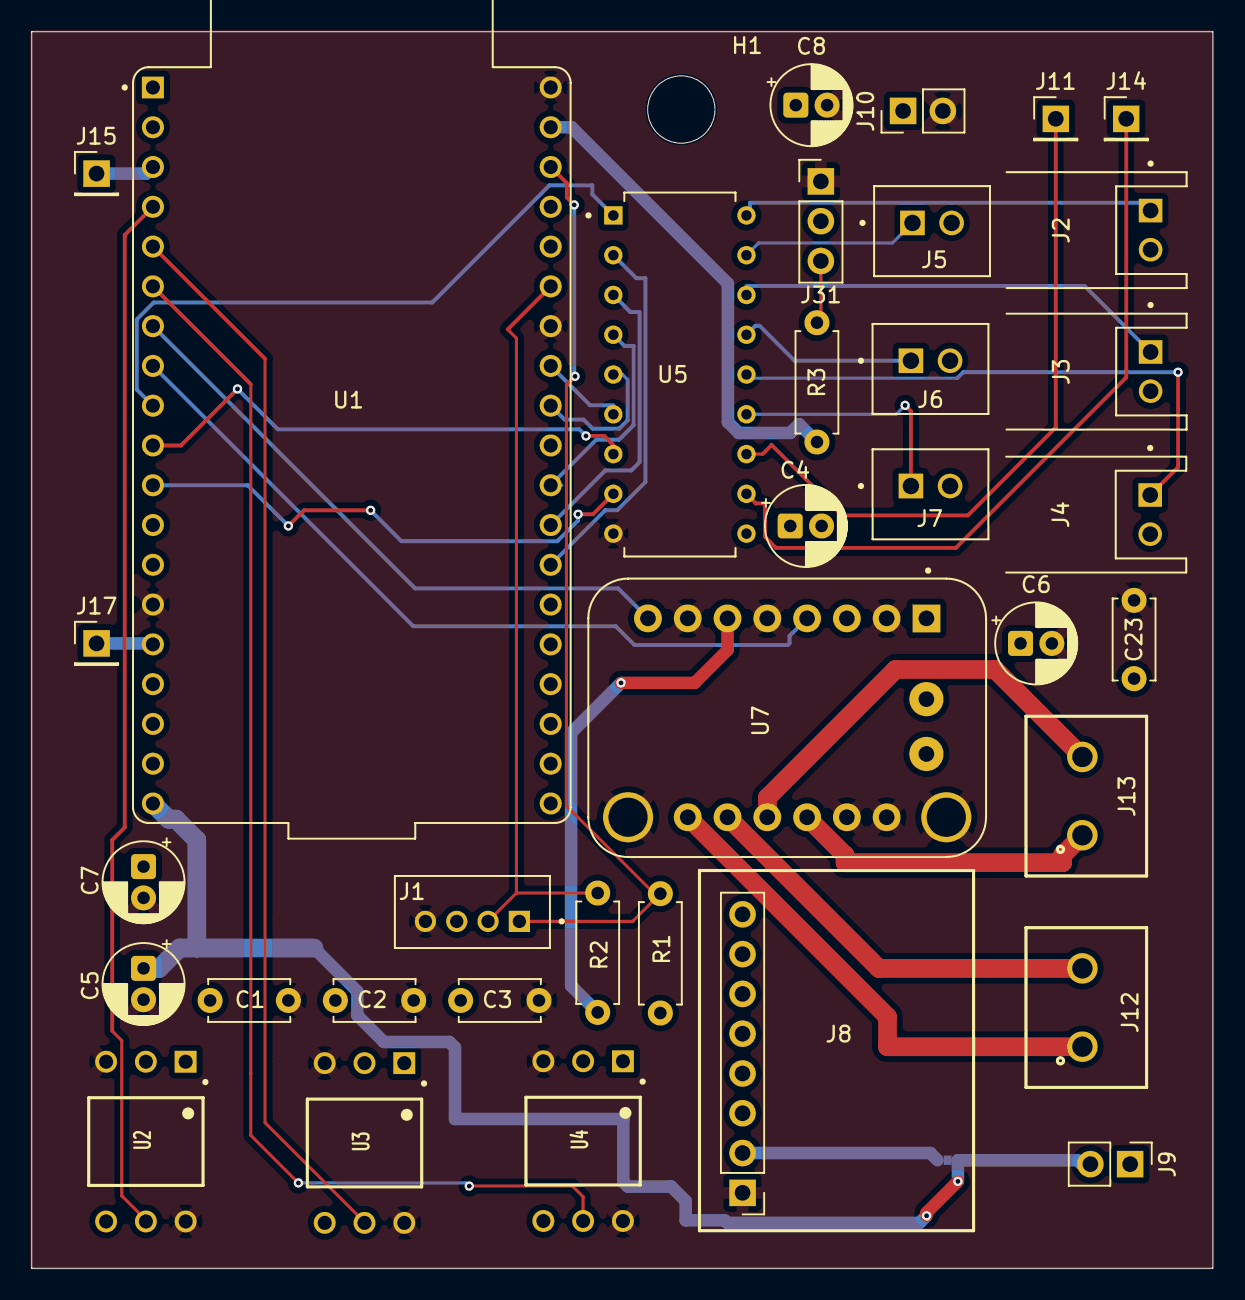
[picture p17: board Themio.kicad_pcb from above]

Board: 4 copper layers, 75.4 x 79.0 mm, 37 parts (1 on the bottom side), 35 nets.

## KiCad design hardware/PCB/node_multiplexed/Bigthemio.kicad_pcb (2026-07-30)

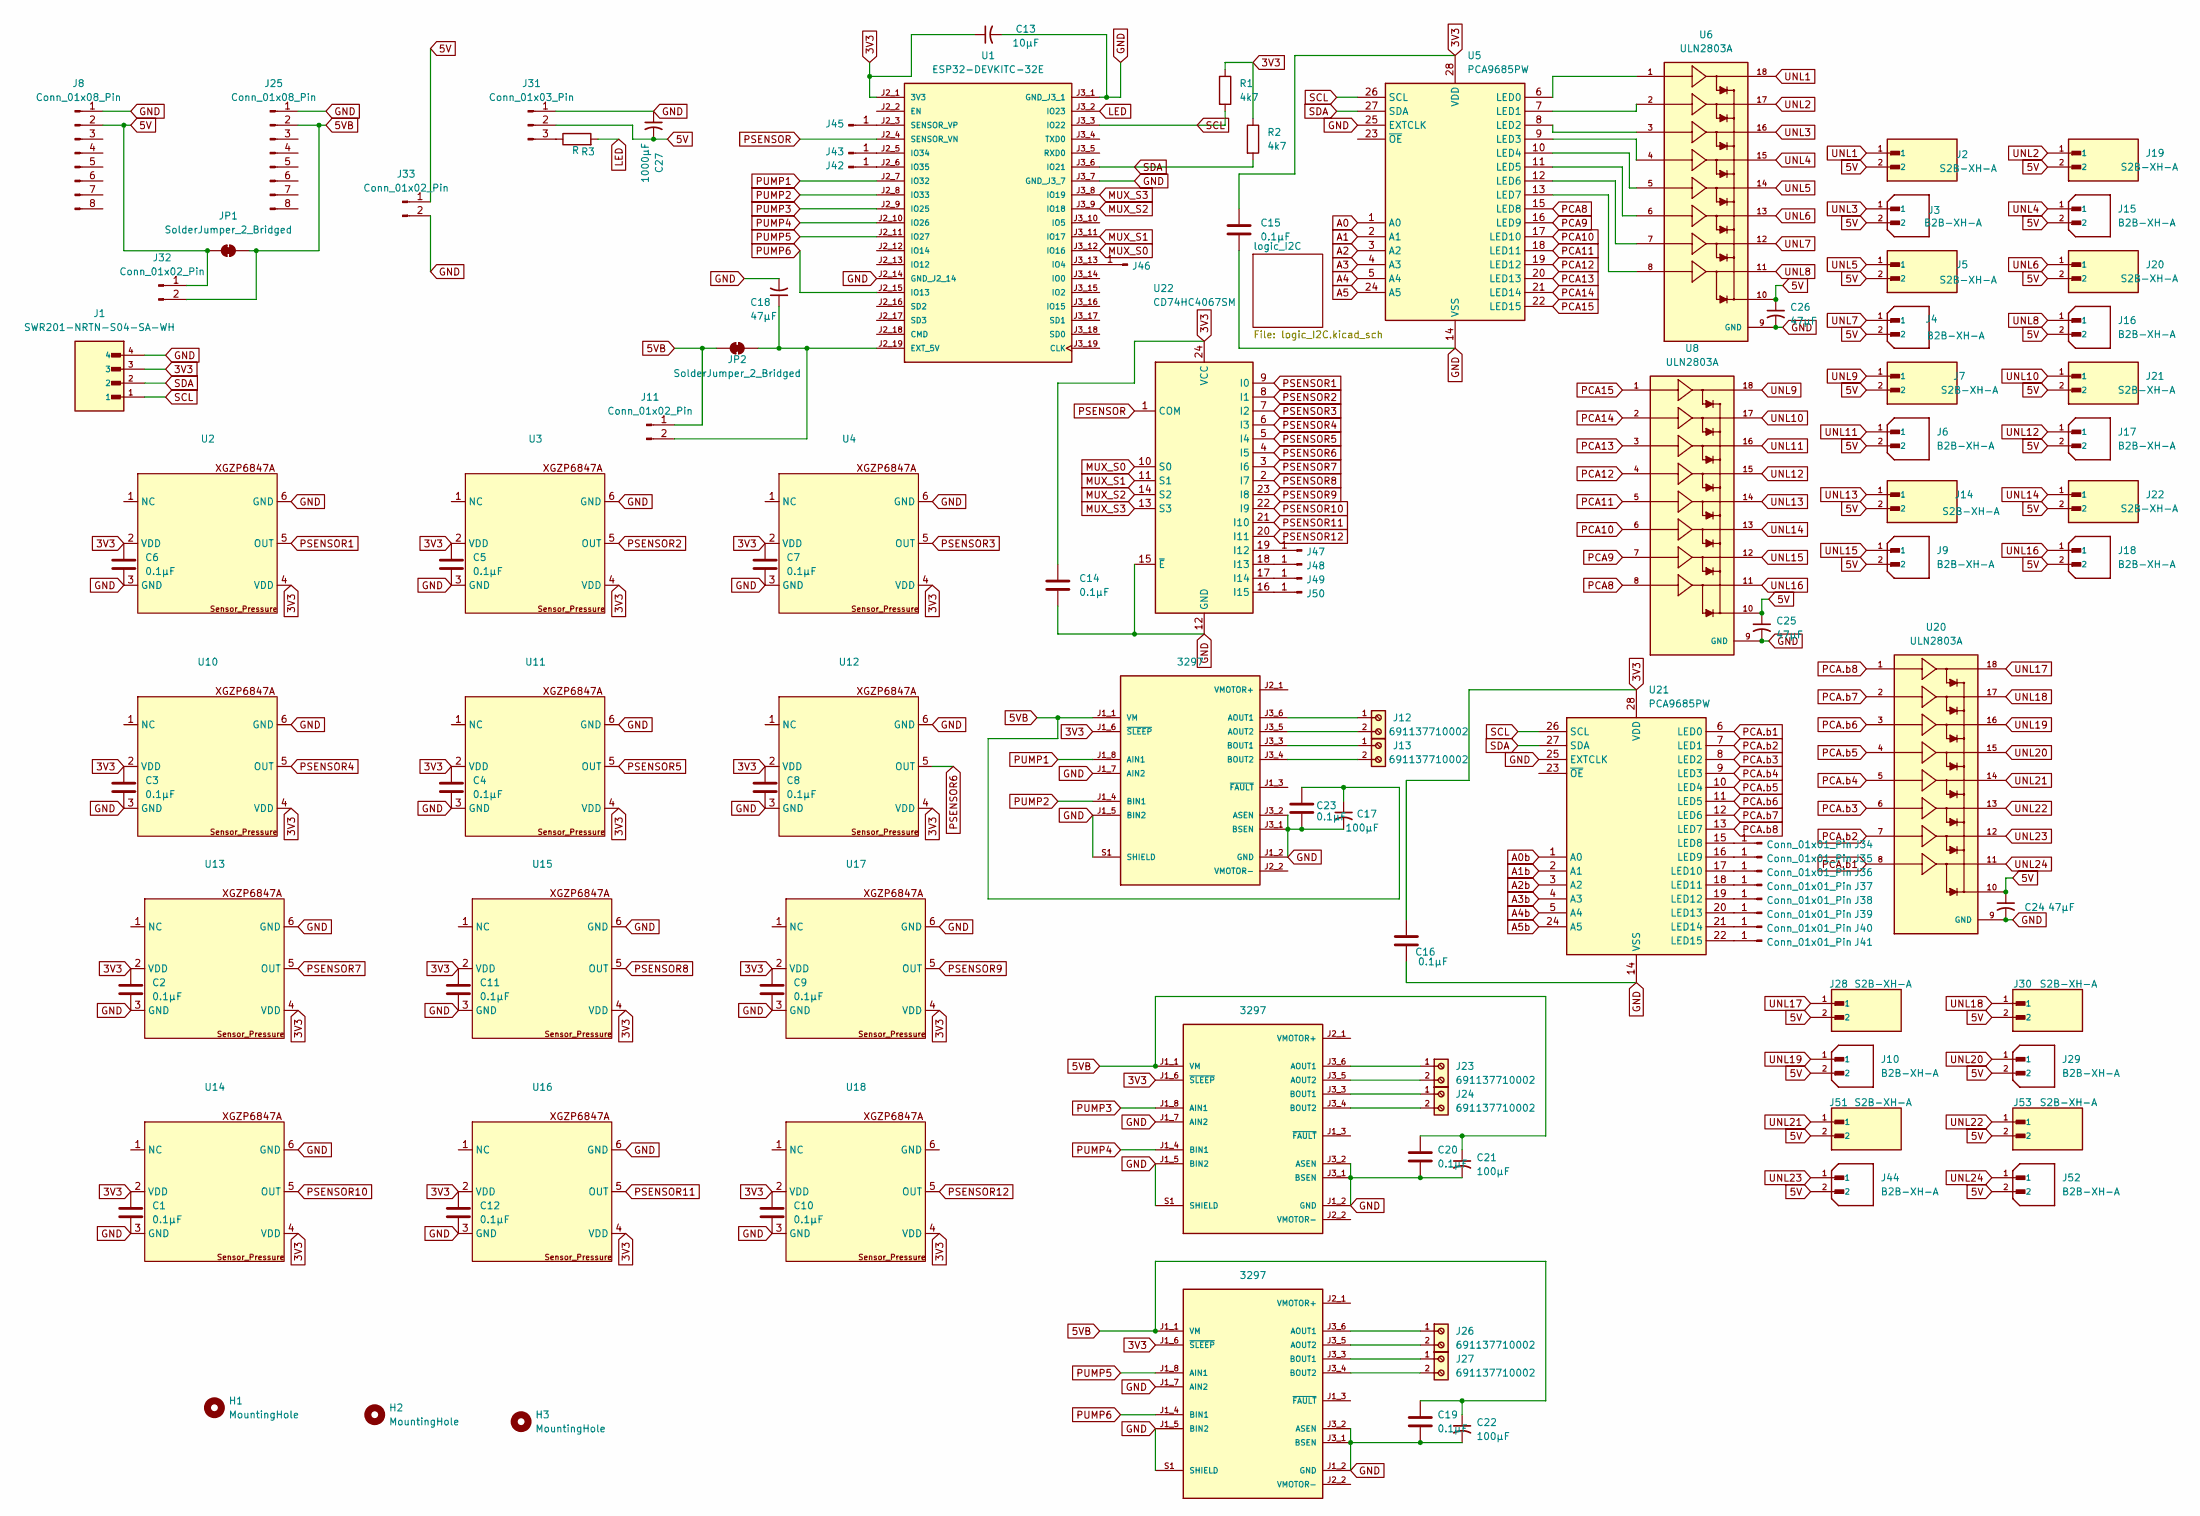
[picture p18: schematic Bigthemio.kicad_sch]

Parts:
C1, C2, C3, C4, C5, C6, C7, C8, C9, C10, C11, C12, C14, C15, C16, C19, C20, C23: 0.1µF; C_Disc_D5.0mm_W2.5mm_P5.00mm
C13: 10µF; CP_Radial_D5.0mm_P2.00mm
C17, C21, C22: 100µF; CP_Radial_D5.0mm_P2.00mm
C18, C24, C25, C26: 47µF; CP_Radial_D5.0mm_P2.00mm
C27: 1000µF; CP_Radial_D5.0mm_P2.00mm
H1, H2, H3: MountingHole; MountingHole_4.3mm_M4
J1: SWR201-NRTN-S04-SA-WH; SULLINS_SWR201-NRTN-S04-SA-WH; PARTREV A
J2, J5, J7, J14, J19, J20, J21, J22, J28, J30, J51, J53: S2B-XH-A; JST_S2B-XH-A
J3, J4, J6, J9, J10, J15, J16, J17, J18, J29, J44, J52: B2B-XH-A; JST_B2B-XH-A; PARTREV N/A
J8, J25: Conn_01x08_Pin; PinHeader_1x08_P2.54mm_Vertical
J11, J32, J33: Conn_01x02_Pin; PinHeader_1x02_P2.54mm_Vertical
J12, J13, J23, J24, J26, J27: 691137710002
J31: Conn_01x03_Pin; PinHeader_1x03_P2.54mm_Vertical
J34, J35, J36, J37, J38, J39, J40, J41, J42, J43, J45, J46, J47, J48, J49, J50: Conn_01x01_Pin; PinHeader_1x01_P2.54mm_Vertical
JP1, JP2: SolderJumper_2_Bridged; SolderJumper-2_P1.3mm_Bridged2Bar_RoundedPad1.0x1.5mm
R1, R2: 4k7; R_Axial_DIN0207_L6.3mm_D2.5mm_P7.62mm_Horizontal
R3: R; R_Axial_DIN0207_L6.3mm_D2.5mm_P7.62mm_Horizontal
U1: ESP32-DEVKITC-32E; MODULE_ESP32-DEVKITC-32E; PARTREV 1.4
U2, U3, U4, U10, U11, U12, U13, U14, U15, U16, U17, U18: XGP6847A_TiagoDias
U5, U21: PCA9685PW; TSSOP-28_4.4x9.7mm_P0.65mm
U6, U8, U20: ULN2803A; UNL; PARTREV 4
U7, U9, U19: 3297; MODULE_3297; PARTREV 2020-11-20
U22: CD74HC4067SM; SSOP-24_5.3x8.2mm_P0.65mm

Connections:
3V3: C1.1, C2.1, C3.1, C4.1, C5.1, C6.1, C7.1, C8.1, C9.1, C10.1, C11.1, C12.1, C13.1, C14.1, C15.1, C16.1, J1.3, R1.1, R2.1, U1.J2_1 (3V3), U2.2 (VDD), U2.4 (VDD), U3.2 (VDD), U3.4 (VDD), U4.2 (VDD), U4.4 (VDD), U5.28 (VDD), U7.J1_6 (~SLEEP), U9.J1_6 (~SLEEP), U10.2 (VDD), U10.4 (VDD), U11.2 (VDD), U11.4 (VDD), U12.2 (VDD), U12.4 (VDD), U13.2 (VDD), U13.4 (VDD), U14.2 (VDD), U14.4 (VDD), U15.2 (VDD), U15.4 (VDD), U16.2 (VDD), U16.4 (VDD), U17.2 (VDD), U17.4 (VDD), U18.2 (VDD), U18.4 (VDD), U19.J1_6 (~SLEEP), U21.28 (VDD), U22.24 (VCC); also elsewhere on the board
5V: C24.1, C25.1, C26.1, C27.2, J2.2, J3.2, J4.2, J5.2, J6.2, J7.2, J8.2, J9.2, J10.2, J14.2, J15.2, J16.2, J17.2, J18.2, J19.2, J20.2, J21.2, J22.2, J28.2, J29.2, J30.2, J31.2, J32.1, J33.1, J44.2, J51.2, J52.2, J53.2, JP1.1 (A), U6.10, U8.10, U20.10
5VB: C17.1, C19.1, C20.1, C21.1, C22.1, C23.1, J11.1, J25.2, J32.2, JP1.2 (B), JP2.1 (A), U7.J1_1 (VM), U9.J1_1 (VM), U19.J1_1 (VM)
A0: U5.1 (A0); also elsewhere on the board
A0b: U21.1 (A0); also elsewhere on the board
A1: U5.2 (A1); also elsewhere on the board
A1b: U21.2 (A1); also elsewhere on the board
A2: U5.3 (A2); also elsewhere on the board
A2b: U21.3 (A2); also elsewhere on the board
A3: U5.4 (A3); also elsewhere on the board
A3b: U21.4 (A3); also elsewhere on the board
A4: U5.5 (A4); also elsewhere on the board
A4b: U21.5 (A4); also elsewhere on the board
A5: U5.24 (A5); also elsewhere on the board
A5b: U21.24 (A5); also elsewhere on the board
GND: C1.2, C2.2, C3.2, C4.2, C5.2, C6.2, C7.2, C8.2, C9.2, C10.2, C11.2, C12.2, C13.2, C14.2, C15.2, C16.2, C17.2, C18.2, C19.2, C20.2, C21.2, C22.2, C23.2, C24.2, C25.2, C26.2, C27.1, J1.4, J8.1, J25.1, J31.1, J33.2, U1.J2_14 (GND_J2_14), U1.J3_1 (GND_J3_1), U1.J3_7 (GND_J3_7), U2.3 (GND), U2.6 (GND), U3.3 (GND), U3.6 (GND), U4.3 (GND), U4.6 (GND), U5.14 (VSS), U5.25 (EXTCLK), U6.9 (GND), U7.J1_2 (GND), U7.J1_5 (BIN2), U7.J1_7 (AIN2), U7.J3_1 (BSEN), U7.J3_2 (ASEN), U7.S1 (SHIELD), U7.S2 (SHIELD), U8.9 (GND), U9.J1_2 (GND), U9.J1_5 (BIN2), U9.J1_7 (AIN2), U9.J3_1 (BSEN), U9.J3_2 (ASEN), U9.S1 (SHIELD), U9.S2 (SHIELD), U10.3 (GND), U10.6 (GND), U11.3 (GND), U11.6 (GND), U12.3 (GND), U12.6 (GND), U13.3 (GND), U13.6 (GND), U14.3 (GND), U14.6 (GND), U15.3 (GND), U15.6 (GND), U16.3 (GND), U16.6 (GND), U17.3 (GND), U17.6 (GND), U18.3 (GND), U19.J1_2 (GND), U19.J1_5 (BIN2), U19.J1_7 (AIN2), U19.J3_1 (BSEN), U19.J3_2 (ASEN), U19.S1 (SHIELD), U19.S2 (SHIELD), U20.9 (GND), U21.14 (VSS), U21.25 (EXTCLK), U22.12 (GND), U22.15 (~E); also elsewhere on the board
LED: R3.2, U1.J3_2 (IO23)
MUX_S0: U1.J3_12 (IO16), U22.10 (S0)
MUX_S1: U1.J3_11 (IO17), U22.11 (S1)
MUX_S2: U1.J3_9 (IO18), U22.14 (S2)
MUX_S3: U1.J3_8 (IO19), U22.13 (S3)
unnamed: C18.1, J11.2, JP2.2 (B), U1.J2_19 (EXT_5V)
unnamed: J31.3, R3.1
unnamed: J34.1, U21.15 (LED8)
unnamed: J35.1, U21.16 (LED9)
unnamed: J36.1, U21.17 (LED10)
unnamed: J37.1, U21.18 (LED11)
unnamed: J38.1, U21.19 (LED12)
unnamed: J39.1, U21.20 (LED13)
unnamed: J40.1, U21.21 (LED14)
unnamed: J41.1, U21.22 (LED15)
unnamed: J42.1, U1.J2_6 (IO35)
unnamed: J43.1, U1.J2_5 (IO34)
unnamed: J45.1, U1.J2_3 (SENSOR_VP)
unnamed: J46.1, U1.J3_13 (IO4)
unnamed: J47.1, U22.19 (I12)
unnamed: J48.1, U22.18 (I13)
unnamed: J49.1, U22.17 (I14)
unnamed: J50.1, U22.16 (I15)
unnamed: U5.6 (LED0), U6.1
unnamed: U5.7 (LED1), U6.2
unnamed: U5.8 (LED2), U6.3
unnamed: U5.9 (LED3), U6.4
unnamed: U5.10 (LED4), U6.5
unnamed: U5.11 (LED5), U6.6
unnamed: U5.12 (LED6), U6.7
unnamed: U5.13 (LED7), U6.8
unnamed: J12.1, U7.J3_6 (AOUT1)
unnamed: J12.2, U7.J3_5 (AOUT2)
unnamed: J13.1, U7.J3_3 (BOUT1)
unnamed: J13.2, U7.J3_4 (BOUT2)
unnamed: J23.1, U9.J3_6 (AOUT1)
unnamed: J23.2, U9.J3_5 (AOUT2)
unnamed: J24.1, U9.J3_3 (BOUT1)
unnamed: J24.2, U9.J3_4 (BOUT2)
unnamed: J26.1, U19.J3_6 (AOUT1)
unnamed: J26.2, U19.J3_5 (AOUT2)
unnamed: J27.1, U19.J3_3 (BOUT1)
unnamed: J27.2, U19.J3_4 (BOUT2)
PCA8: U5.15 (LED8), U8.8
PCA9: U5.16 (LED9), U8.7
PCA10: U5.17 (LED10), U8.6
PCA11: U5.18 (LED11), U8.5
PCA12: U5.19 (LED12), U8.4
PCA13: U5.20 (LED13), U8.3
PCA14: U5.21 (LED14), U8.2
PCA15: U5.22 (LED15), U8.1
PCA.b1: U20.8, U21.6 (LED0)
PCA.b2: U20.7, U21.7 (LED1)
PCA.b3: U20.6, U21.8 (LED2)
PCA.b4: U20.5, U21.9 (LED3)
PCA.b5: U20.4, U21.10 (LED4)
PCA.b6: U20.3, U21.11 (LED5)
PCA.b7: U20.2, U21.12 (LED6)
PCA.b8: U20.1, U21.13 (LED7)
PSENSOR: U1.J2_4 (SENSOR_VN), U22.1 (COM)
PSENSOR1: U2.5 (OUT), U22.9 (I0)
PSENSOR2: U3.5 (OUT), U22.8 (I1)
PSENSOR3: U4.5 (OUT), U22.7 (I2)
PSENSOR4: U10.5 (OUT), U22.6 (I3)
PSENSOR5: U11.5 (OUT), U22.5 (I4)
PSENSOR6: U12.5 (OUT), U22.4 (I5)
PSENSOR7: U13.5 (OUT), U22.3 (I6)
PSENSOR8: U15.5 (OUT), U22.2 (I7)
PSENSOR9: U17.5 (OUT), U22.23 (I8)
PSENSOR10: U14.5 (OUT), U22.22 (I9)
PSENSOR11: U16.5 (OUT), U22.21 (I10)
PSENSOR12: U18.5 (OUT), U22.20 (I11)
PUMP1: U1.J2_7 (IO32), U7.J1_8 (AIN1)
PUMP2: U1.J2_8 (IO33), U7.J1_4 (BIN1)
PUMP3: U1.J2_9 (IO25), U9.J1_8 (AIN1)
PUMP4: U1.J2_10 (IO26), U9.J1_4 (BIN1)
PUMP5: U1.J2_11 (IO27), U19.J1_8 (AIN1)
PUMP6: U1.J2_15 (IO13), U19.J1_4 (BIN1)
SCL: J1.1, R1.2, U1.J3_3 (IO22), U5.26 (SCL), U21.26 (SCL)
SDA: J1.2, R2.2, U1.J3_6 (IO21), U5.27 (SDA), U21.27 (SDA)
UNL1: J2.1, U6.18
UNL2: J19.1, U6.17
UNL3: J3.1, U6.16
UNL4: J15.1, U6.15
UNL5: J5.1, U6.14
UNL6: J20.1, U6.13
UNL7: J4.1, U6.12
UNL8: J16.1, U6.11
UNL9: J7.1, U8.18
UNL10: J21.1, U8.17
UNL11: J6.1, U8.16
UNL12: J17.1, U8.15
UNL13: J14.1, U8.14
UNL14: J22.1, U8.13
UNL15: J9.1, U8.12
UNL16: J18.1, U8.11
UNL17: J28.1, U20.18
UNL18: J30.1, U20.17
UNL19: J10.1, U20.16
UNL20: J29.1, U20.15
UNL21: J51.1, U20.14
UNL22: J53.1, U20.13
UNL23: J44.1, U20.12
UNL24: J52.1, U20.11

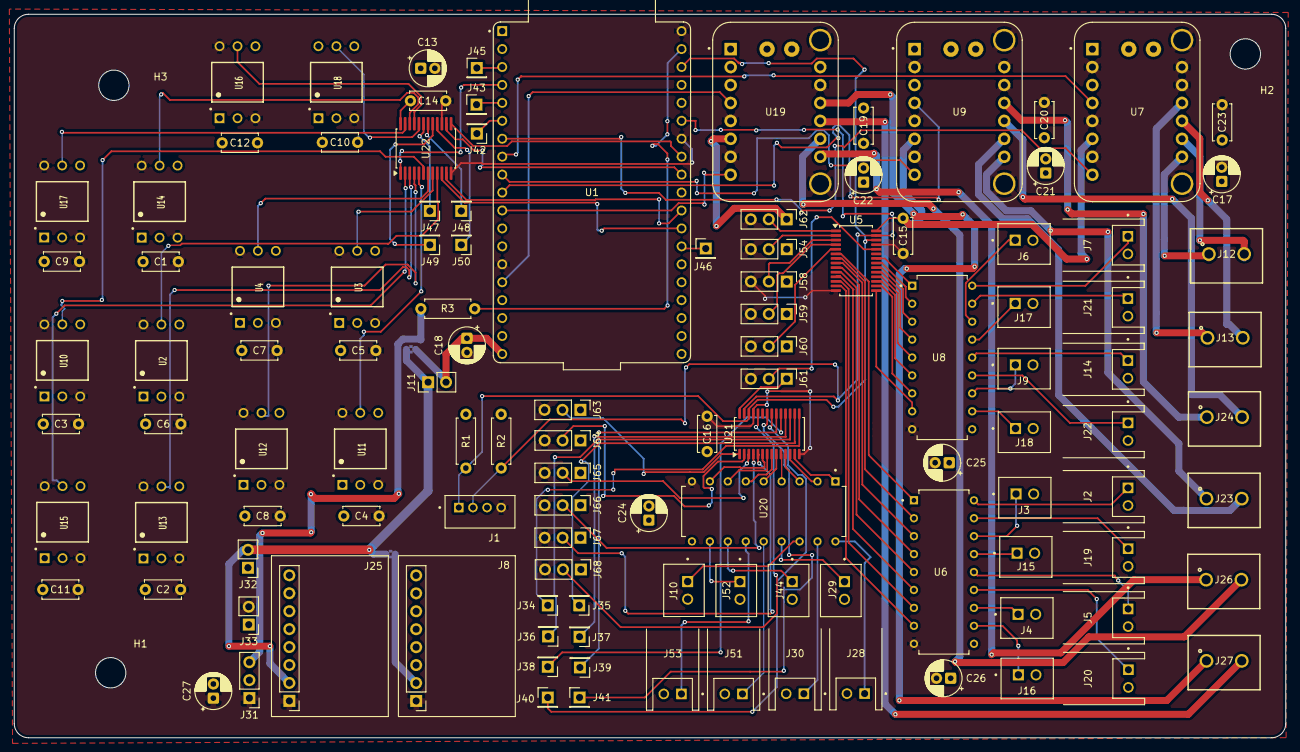
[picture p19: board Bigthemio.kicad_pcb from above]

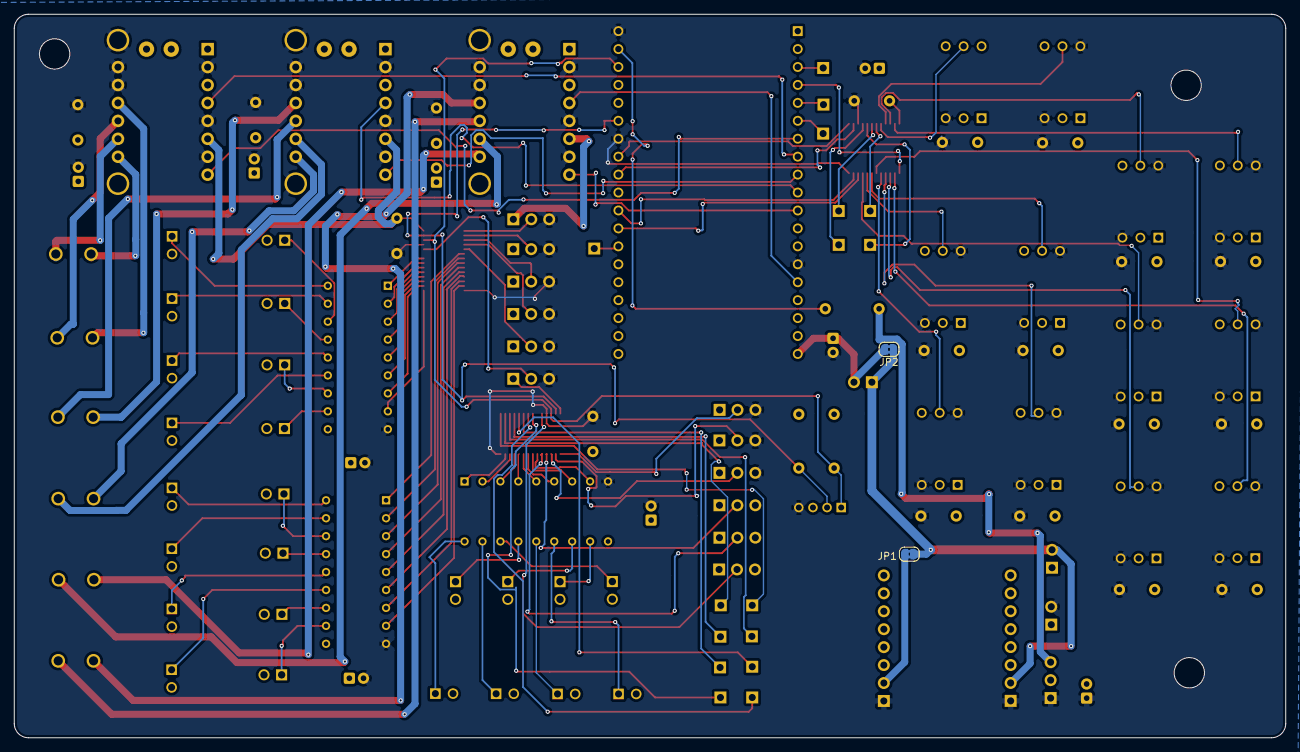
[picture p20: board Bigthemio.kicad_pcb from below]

Board: 4 copper layers, 180.1 x 102.5 mm, 122 parts (2 on the bottom side), 120 nets.

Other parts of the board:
J54, J58, J59, J60, J61, J62, J63, J64, J65, J66, J67, J68: Conn_01x03_Pin; PinHeader_1x03_P2.54mm_Vertical

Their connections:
3V3: J54.1, J58.1, J59.1, J60.1, J61.1, J62.1, J63.1, J64.1, J65.1, J66.1, J67.1, J68.1; also elsewhere on the board
A0: J62.2; also elsewhere on the board
A0b: J63.2; also elsewhere on the board
A1: J54.2; also elsewhere on the board
A1b: J64.2; also elsewhere on the board
A2: J58.2; also elsewhere on the board
A2b: J65.2; also elsewhere on the board
A3: J59.2; also elsewhere on the board
A3b: J66.2; also elsewhere on the board
A4: J60.2; also elsewhere on the board
A4b: J67.2; also elsewhere on the board
A5: J61.2; also elsewhere on the board
A5b: J68.2; also elsewhere on the board
GND: J54.3, J58.3, J59.3, J60.3, J61.3, J62.3, J63.3, J64.3, J65.3, J66.3, J67.3, J68.3; also elsewhere on the board

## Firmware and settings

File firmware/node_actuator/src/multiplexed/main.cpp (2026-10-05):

#include <Arduino.h>
#include <ArduinoJson.h>
#include <esp_ota_ops.h>

#include "se_espnow.h"
#include "se_ota.h"
#include "chambers.h"
#include "cmd_queue.h"
#include "config.h"
#include "dbg.h"
#include "leds.h"
#include "mux.h"
#include "organ.h"
#include "pca_valves.h"
#include "pins.h"
#include "pumps.h"
#include "units.h"

namespace {

// Idle gauge sweep: every chamber, median of 3 mux reads each (~3 ms for 12).
// 25 ms = 40 Hz per sensor, so each 500 ms status averages ~20 reads.
constexpr uint32_t PRESSURE_CHECK_MS = 25;
constexpr uint32_t STATUS_REPORT_MS  = 500;

// The closed-loop chamber cutoff runs MUCH tighter than the idle gauge refresh /
// telemetry. A chamber's inflate pump runs at full duty the whole time it is
// INFLATING, so the achieved pressure overshoots the target by however much is
// delivered between two checks: at 200 ms a single "+" step (e.g. +10 % of range)
// blew past to ~30 % before the cutoff looked at the sensor. 20 ms shrinks that
// window ~10x so the measured level settles on the commanded target (mirrors
// node_direct). The idle refresh runs on PRESSURE_CHECK_MS.
constexpr uint32_t CHAMBER_CHECK_MS  = 20;

uint32_t lastPressureMs = 0;
uint32_t lastChamberMs  = 0;
uint32_t lastStatusMs = 0;

// Gateway MAC tracking lives in the shared ESP-NOW layer.
using se::node::gatewayMac;
using se::node::gatewayKnown;
bool configured = false;

// Emergency stop: when latched, loop() forces pumps off + valves closed and
// skips all autonomous control until a "resume" command clears it.
bool emergencyStopped = false;

// Organ channels arrive inside `configure` but are applied from loop() (not
// the ESP-NOW receive task) so organ::tick never races a reconfiguration.
int pendingOrganCh[organ::MAX_ORGANS] = {};
volatile int pendingOrganCount = -1;   // -1 = nothing pending

void sendRaw(const char* payload) {
    if (!gatewayKnown) return;
    esp_now_send(gatewayMac, reinterpret_cast<const uint8_t*>(payload), strlen(payload));
}

void sendError(const char* reason) {
    char buf[96];
    int len = snprintf(buf, sizeof(buf), "{\"type\":\"error\",\"reason\":\"%s\"}", reason);
    if (gatewayKnown) {
        esp_now_send(gatewayMac, reinterpret_cast<const uint8_t*>(buf), len);
    }
}

void sendPong() {
    // "kpa_min" self-reports the gauge floor (sensor low end) so the PC knows
    // below which pressure a deflate needs a time budget instead of the sensor.
    char pong[96];
    snprintf(pong, sizeof(pong),
             "{\"type\":\"pong\",\"rgbw\":" LED_RGBW_JSON ",\"kpa_min\":%.0f}",
             (double)pressure::FLOOR_KPA);
    sendRaw(pong);
}

// Batched status: every chamber in ONE frame (parallel arrays) instead of one esp_now_send
// per chamber. Cuts the status frame count num_chambersx - the biggest win during a
// status_rate fast window - freeing ESP-NOW airtime the Thymio's co-channel 802.15.4
// shares. "pressure" is omitted (redundant - the PC recomputes it from "kpa"; kpa is
// authoritative). Even a full 12-chamber frame is ~200 B, under the 250 B ESP-NOW limit,
// so it is always a single frame (no splitting). kpa at 0.1 kPa. The PC still parses the
// old scalar per-chamber frame for nodes flashed before batching.
void sendStatusAll() {
    if (!gatewayKnown) return;
    const int n = config::state.num_chambers;
    char buf[256];
    int len = snprintf(buf, sizeof(buf), "{\"type\":\"status\",\"kpa\":[");
    for (int i = 0; i < n; i++)
        len += snprintf(buf + len, sizeof(buf) - len, "%s%.1f", i ? "," : "",
                        chambers::takeWindowKpa(i));
    len += snprintf(buf + len, sizeof(buf) - len, "],\"st\":[");
    for (int i = 0; i < n; i++)
        len += snprintf(buf + len, sizeof(buf) - len, "%s%d", i ? "," : "",
                        (int)chambers::state[i].state);
    len += snprintf(buf + len, sizeof(buf) - len, "],\"vi\":[");
    for (int i = 0; i < n; i++)
        len += snprintf(buf + len, sizeof(buf) - len, "%s%d", i ? "," : "",
                        pca_valves::isOpen(i, 0) ? 1 : 0);
    len += snprintf(buf + len, sizeof(buf) - len, "],\"vd\":[");
    for (int i = 0; i < n; i++)
        len += snprintf(buf + len, sizeof(buf) - len, "%s%d", i ? "," : "",
                        pca_valves::isOpen(i, 1) ? 1 : 0);
    len += snprintf(buf + len, sizeof(buf) - len, "]}");
    esp_now_send(gatewayMac, reinterpret_cast<const uint8_t*>(buf), len);
}

#ifdef DEBUG_BUILD
// Which valves are open the instant an actuation command lands (the info the user
// wants kept), streamed over ESP-NOW so it lands in the PC log without a cable.
void sendRxOpen(const char* cmd, int chamber) {
    if (!gatewayKnown) return;
    uint16_t inf = 0, def = 0;
    for (int i = 0; i < MAX_CHAMBERS; i++) {
        if (pca_valves::isOpen(i, 0)) inf |= (uint16_t)(1u << i);
        if (pca_valves::isOpen(i, 1)) def |= (uint16_t)(1u << i);
    }
    char buf[112];
    int len = snprintf(buf, sizeof(buf),
        "{\"type\":\"dbg\",\"ev\":\"rx\",\"cmd\":\"%s\",\"ch\":%d,\"open_inf\":%d,\"open_def\":%d}",
        cmd, chamber, inf, def);
    esp_now_send(gatewayMac, reinterpret_cast<const uint8_t*>(buf), len);
}

// Engine round/measure trace (coupled_fill::Event), registered as chambers::dbgHook.
void sendEngEvent(uint8_t ev, uint16_t mask, uint8_t dir) {
    if (!gatewayKnown) return;
    char buf[80];
    int len = snprintf(buf, sizeof(buf),
        "{\"type\":\"dbg\",\"ev\":\"eng\",\"dir\":%d,\"code\":%d,\"mask\":%d}", dir, ev, mask);
    esp_now_send(gatewayMac, reinterpret_cast<const uint8_t*>(buf), len);
}

// Pump-vs-valve sanity: report a pump role running with NO open valve (dead-head,
// the "running dry / forcing" failure) OR more pumps running than the open valves
// should need (forcing the manifold). recalcPumps() should make both impossible -
// this only fires on a regression.
void checkDryPumps() {
    if (!gatewayKnown) return;
    int openInf = 0, openDef = 0;
    for (int i = 0; i < MAX_CHAMBERS; i++) {
        if (pca_valves::isOpen(i, 0)) openInf++;
        if (pca_valves::isOpen(i, 1)) openDef++;
    }
    int runP = 0, runV = 0;
    for (int i = 0; i < NUM_PUMPS; i++) {
        if (ledcRead(i) == 0) continue;
        if (pumps::roles[i] == pumps::ROLE_PRESSURE) runP++;
        else if (pumps::roles[i] == pumps::ROLE_VACUUM) runV++;
    }
    const int VPP = chambers::VALVES_PER_PUMP;
    int wantP = openInf > 0 ? (openInf + VPP - 1) / VPP : 0;
    int wantV = openDef > 0 ? (openDef + VPP - 1) / VPP : 0;
    if (runP <= wantP && runV <= wantV) return;
    char buf[136];
    int len = snprintf(buf, sizeof(buf),
        "{\"type\":\"dbg\",\"ev\":\"dry\",\"runP\":%d,\"wantP\":%d,\"openInf\":%d,\"runV\":%d,\"wantV\":%d,\"openDef\":%d}",
        runP, wantP, openInf, runV, wantV, openDef);
    esp_now_send(gatewayMac, reinterpret_cast<const uint8_t*>(buf), len);
}

void installDebugHook() { chambers::dbgHook = &sendEngEvent; }

// Raw ADC counts of all 16 mux inputs, once per status. Shows which inputs
// carry a sensor and its ambient offset - the kPa status clamps at the gauge
// floor, so a sensor whose ambient output sits below the nominal zero reads
// 0 there, indistinguishable from an empty input.
void sendRawAdc() {
    char buf[128];
    int len = snprintf(buf, sizeof(buf), "{\"type\":\"raw\",\"adc\":[");
    for (int ch = 0; ch < mux::MUX_CHANNELS; ch++)
        len += snprintf(buf + len, sizeof(buf) - len, "%s%d", ch ? "," : "", mux::readRaw(ch));
    len += snprintf(buf + len, sizeof(buf) - len, "]}");
    sendRaw(buf);
}
#endif

bool isDisconnectedRail(int raw) {
    return raw < 40 || raw > 4055;
}

void detectSensors(int valid_channels[], int& valid_count) {
    valid_count = 0;

    for (int ch = 0; ch < mux::MUX_CHANNELS; ch++) {
        int raw = mux::readRaw(ch);
        if (isDisconnectedRail(raw)) {
            continue;
        }

        float r0 = mux::readKpa(ch);
        float r1 = mux::readKpa(ch);
        float r2 = mux::readKpa(ch);
        float lo = min(r0, min(r1, r2));
        float hi = max(r0, max(r1, r2));
        if ((hi - lo) > 1.0f) {
            continue;
        }

        valid_channels[valid_count++] = ch;
    }

    // Fixed mapping: chamber i reads mux channel Ii (PSENSOR i+1), the same
    // index its valves use (UNL 2i+1 / 2i+2). The scan above is diagnostic only:
    // packing the responders into chambers 0..n-1 put a sensor under the wrong
    // chamber's valves and left a chamber blind whenever one read out of range
    // at boot (unsoldered, noisy, or not yet settled).
    config::state.num_chambers = max(1, min(valid_count, MAX_CHAMBERS));
    for (int i = 0; i < MAX_CHAMBERS; i++) {
        config::state.chamber_mux_ch[i] = i;
    }

    char channels[96] = {0};
    int pos = 0;
    for (int i = 0; i < valid_count && pos < static_cast<int>(sizeof(channels)) - 8; i++) {
        pos += snprintf(channels + pos, sizeof(channels) - pos, "%s%d", i == 0 ? "" : ",", valid_channels[i]);
    }
    LOG("Sensors responding at mux channels: %s\n", channels);
}

// No reservoir tanks: the pumps push directly into the chambers, so their role
// (pressure = inflate, vacuum = deflate) can't be discovered by watching a tank
// sensor. Split the pumps evenly by default - first half PRESSURE, second half
// VACUUM (e.g. 3 + 3 of NUM_PUMPS = 6) - which the gateway's `configure`
// (pump_groups / pump_inflate_count / pump_deflate_count) overrides with the real
// wiring. There are no tank sensors to assign.
void assignDefaultPumpRoles() {
    config::state.pressure_tank_mux_ch = -1;
    config::state.vacuum_tank_mux_ch = -1;
    for (int i = 0; i < NUM_PUMPS; i++) {
        pumps::roles[i] = (i < NUM_PUMPS / 2) ? pumps::ROLE_PRESSURE : pumps::ROLE_VACUUM;
    }
    LOG("Default pump roles: PUMP1..%d pressure, rest vacuum (override via configure)\n",
        NUM_PUMPS / 2);
}

void applyPumpGroups(uint8_t pressure_mask, uint8_t vacuum_mask) {
    for (int i = 0; i < NUM_PUMPS; i++) {
        bool in_pressure = (pressure_mask & (1u << i)) != 0;
        bool in_vacuum = (vacuum_mask & (1u << i)) != 0;
        if (in_pressure && !in_vacuum) {
            pumps::roles[i] = pumps::ROLE_PRESSURE;
        } else if (in_vacuum && !in_pressure) {
            pumps::roles[i] = pumps::ROLE_VACUUM;
        }
    }
}

void parseAndQueue(const uint8_t* data, int len) {
    JsonDocument doc;
    if (deserializeJson(doc, data, len) != DeserializationError::Ok) {
        return;
    }

    const char* cmd = doc["cmd"] | "";
    cmd_queue::Cmd c{};

    if (strcmp(cmd, "ping") == 0) {
        c.type = cmd_queue::CMD_PING;
        c.chamber = -1;
    } else if (strcmp(cmd, "inflate") == 0) {
        c.type = cmd_queue::CMD_INFLATE;
        c.chamber = cmd_queue::chamberArg(doc["chamber"] | -1);
        c.param = doc["delta"] | 10;
        c.fill_ms = doc["ms"] | 0;
        c.duty = doc["duty"] | 0;
        c.timed = doc["timed"] | 0;
    } else if (strcmp(cmd, "deflate") == 0) {
        c.type = cmd_queue::CMD_DEFLATE;
        c.chamber = cmd_queue::chamberArg(doc["chamber"] | -1);
        c.param = doc["delta"] | 10;
        c.fill_ms = doc["ms"] | 0;
        c.duty = doc["duty"] | 0;
        c.timed = doc["timed"] | 0;
    } else if (strcmp(cmd, "set_pressure") == 0) {
        c.type = cmd_queue::CMD_SET_PRESSURE;
        c.chamber = cmd_queue::chamberArg(doc["chamber"] | -1);
        c.param = doc["value"] | 0;
        c.duty = doc["duty"] | 0;
    } else if (strcmp(cmd, "set_max_pressure") == 0) {
        c.type = cmd_queue::CMD_SET_MAX;
        c.chamber = cmd_queue::chamberArg(doc["chamber"] | -1);
        c.param_kpa = doc["value"] | config::DEFAULT_CHAMBER_MAX_KPA;
        c.seq = doc["seq"] | cmd_queue::NO_SEQ;
    } else if (strcmp(cmd, "set_min_pressure") == 0) {
        c.type = cmd_queue::CMD_SET_MIN;
        c.chamber = cmd_queue::chamberArg(doc["chamber"] | -1);
        c.param_kpa = doc["value"] | config::DEFAULT_CHAMBER_MIN_KPA;
        c.seq = doc["seq"] | cmd_queue::NO_SEQ;
    } else if (strcmp(cmd, "hold_duty") == 0) {
        // Leak-compensating hold: {"cmd":"hold_duty","chamber":n,"duty":D,
        // "kpa":K?,"timed":1?} starts/refreshes (PC re-sends ~2 s as keepalive);
        // "off":1 drops it (chamber -1 = all). No "kpa" / "timed":1 = duty-only.
        c.type = cmd_queue::CMD_HOLD_DUTY;
        c.chamber = cmd_queue::chamberArg(doc["chamber"] | -1);
        c.duty = doc["duty"] | 0;
        c.param = cmd_queue::holdDutyMode(doc["off"] | 0, doc["ka"] | 0);   // start / off / keepalive refresh
        c.timed = doc["timed"] | 0;
        c.dir = (doc["dir"] | 0) ? 1 : 0;    // 0 = pressure hold, 1 = vacuum hold
        c.param_kpa = doc["kpa"].is<float>() ? doc["kpa"].as<float>() : NAN;
    } else if (strcmp(cmd, "hold") == 0) {
        c.type = cmd_queue::CMD_HOLD;
        c.chamber = cmd_queue::chamberArg(doc["chamber"] | -1);
    } else if (strcmp(cmd, "stop") == 0) {
        c.type = cmd_queue::CMD_STOP;
    } else if (strcmp(cmd, "resume") == 0) {
        c.type = cmd_queue::CMD_RESUME;
    } else if (strcmp(cmd, "tare") == 0) {
        c.type = cmd_queue::CMD_TARE;
        c.chamber = -1;
    } else if (strcmp(cmd, "valve_manual") == 0) {
        c.type = cmd_queue::CMD_VALVE_MANUAL;
        c.chamber = cmd_queue::chamberArg(doc["chamber"] | -1);
        c.param = doc["side"] | 0;     // 0=inflate, 1=deflate
        c.cfg_chambers = doc["open"] | 0;
    } else if (strcmp(cmd, "pump_manual") == 0) {
        c.type = cmd_queue::CMD_PUMP_MANUAL;
        c.param = doc["pump"] | 0;     // 0=pressure, 1=vacuum
        c.cfg_chambers = doc["on"] | 0;
    } else if (strcmp(cmd, "vent") == 0) {
        // Bench vent: both valves of the chamber (-1 = all) open, pumps off it.
        c.type = cmd_queue::CMD_VENT;
        c.chamber = cmd_queue::chamberArg(doc["chamber"] | -1);
        c.cfg_chambers = doc["open"] | 0;
    } else if (strcmp(cmd, "configure") == 0) {
        c.type = cmd_queue::CMD_CONFIGURE;
        c.cfg_chambers = doc["num_chambers"] | config::state.num_chambers;
        c.cfg_p_min    = doc["tank_pressure_min_kpa"]    | config::state.tank_pressure_min_kpa;
        c.cfg_p_max    = doc["tank_pressure_max_kpa"]    | config::state.tank_pressure_max_kpa;
        c.cfg_v_min    = doc["tank_vacuum_min_kpa"]      | config::state.tank_vacuum_min_kpa;
        c.cfg_v_max    = doc["tank_vacuum_max_kpa"]      | config::state.tank_vacuum_max_kpa;
        c.cfg_p_target = doc["tank_pressure_target_kpa"] | config::state.tank_pressure_target_kpa;
        c.cfg_v_target = doc["tank_vacuum_target_kpa"]   | config::state.tank_vacuum_target_kpa;

        int inflate_count = constrain((int)(doc["pump_inflate_count"] | 0), 0, NUM_PUMPS);
        int deflate_count = constrain((int)(doc["pump_deflate_count"] | 0), 0, NUM_PUMPS);

        c.cfg_pressure_mask = 0;
        c.cfg_vacuum_mask = 0;

        JsonObject groups = doc["pump_groups"].as<JsonObject>();
        if (!groups.isNull()) {
            JsonArray pressure = groups["pressure"].as<JsonArray>();
            JsonArray vacuum = groups["vacuum"].as<JsonArray>();
            for (JsonVariant v : pressure) {
                int p = v.as<int>();
                if (p >= 1 && p <= NUM_PUMPS) c.cfg_pressure_mask |= (1u << (p - 1));
            }
            for (JsonVariant v : vacuum) {
                int p = v.as<int>();
                if (p >= 1 && p <= NUM_PUMPS) c.cfg_vacuum_mask |= (1u << (p - 1));
            }
        }

        if (c.cfg_pressure_mask == 0 && c.cfg_vacuum_mask == 0) {
            for (int i = 0; i < inflate_count; i++) c.cfg_pressure_mask |= (1u << i);
            for (int i = inflate_count; i < inflate_count + deflate_count && i < NUM_PUMPS; i++) {
                c.cfg_vacuum_mask |= (1u << i);
            }
        }

        // Organ circuits: list of mux channels; index in the list = slot in
        // the organ broadcasts. Staged here, applied from loop().
        JsonArray organ_channels = doc["organ_channels"].as<JsonArray>();
        if (!organ_channels.isNull()) {
            int count = 0;
            for (JsonVariant v : organ_channels) {
                int ch = v.as<int>();
                if (count < organ::MAX_ORGANS && ch >= 0 && ch < mux::MUX_CHANNELS) {
                    pendingOrganCh[count++] = ch;
                }
            }
            pendingOrganCount = count;
        }
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
void loop() {
    // Run a pending WiFi OTA from the main task (never returns if it starts -
    // the node reboots into the new firmware).
    se::ota::pollWifi();

    // Animate the LED rings (non-blocking, throttled).
    leds::update();

    cmd_queue::Cmd c;
    while (cmd_queue::pop(c)) {
        processCommand(c);
    }

    // Emergency stop or any not-ready state: keep everything off and skip all
    // control. Commands (incl. "resume") were already drained above, so the
    // node can be re-armed.
    uint32_t now = millis();

    if (emergencyStopped || config::state.error || !config::state.ready || !configured) {
        pumps::stopAll();
        pca_valves::closeAllValves();
        // Telemetry keeps flowing while halted: the PC can only see that the
        // node is up (and re-send configure / resume) if status keeps coming.
        refreshGauges(now);
        broadcastTelemetry(now);
        delay(5);
        return;
    }

    // Manual (dev) override: dead-man auto-off every loop (cheap, no I/O). When
    // it fires, autonomous control resumes on the next pressure tick. SIGNED diff:
    // manualTs is set (millis()) in the command drain, after loop() cached `now`,
    // so an unsigned `now - manualTs` would underflow on the first tick and clear
    // the override the instant it was set (manual valve closes itself).
    if (manualActive && (int32_t)(now - manualTs) >= (int32_t)MANUAL_MAX_ON_MS) manualClearAll();

    // ---- Organ + cover sensing (per configured slot) ----
    applyPendingOrganChannels();
    organ::tick(now);

    // ---- Child-safety watchdog: stop runaway actuations (sensor failure) ----
    if (!manualActive) chambers::actuationWatchdog(now);

    // ---- Refresh gauges for telemetry + command-time guards (mirrors
    //      node_direct). The engines and holds do their own fresh reads; this keeps
    //      idle chambers live in status and in the "below/above target?" checks.
    //      In manual override it also enforces the hard limits. ----
    refreshGauges(now);

    // ---- Coupled-fill engines on their own (tight) cadence: open the group
    //      together -> fill to the lowest open target -> close -> settle -> measure
    //      each isolated -> repeat. Reads the mux gauges itself (median-filtered)
    //      and recalcs the count-scaled pumps when valves change. ----
    if (!manualActive && now - lastChamberMs >= CHAMBER_CHECK_MS) {
        lastChamberMs = now;
        chambers::controlTick(now);
        chambers::recalcPumps();
    }

    // ---- Leak-compensating continuous holds (valve open + equilibrium duty).
    //      Suspends itself while the manual override or an engine sequence owns
    //      the manifold (emergencyStopped never reaches here - loop returned). ----
    chambers::holdTick(now, manualActive || chambers::seqActive());

    broadcastTelemetry(now);
}

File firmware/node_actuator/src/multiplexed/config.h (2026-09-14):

#pragma once
#include <Arduino.h>
#include "pins.h"
#include "pressure.h"   // VACUUM_HOLD_FLOOR_KPA (valve-safe vacuum cap)

// Runtime configuration - populated by boot autodetect, optionally overridden
// by the gateway's `configure` command.

namespace config {

constexpr float DEFAULT_TANK_PRESSURE_MAX_KPA =  50.0f;   // hard upper cap for positive tank
constexpr float DEFAULT_TANK_PRESSURE_MIN_KPA =   0.0f;   // never below ambient (negative would mean broken vacuum into pressure tank)
constexpr float DEFAULT_TANK_VACUUM_MAX_KPA   =   0.0f;   // never above ambient (positive would mean broken pressure into vacuum tank)
constexpr float DEFAULT_TANK_VACUUM_MIN_KPA   = -50.0f;   // hard lower cap for vacuum tank
constexpr float HARD_TANK_MAX_KPA             =  80.0f;
constexpr float HARD_TANK_MIN_KPA             = -80.0f;

constexpr float DEFAULT_CHAMBER_MAX_KPA =   8.0f;
constexpr float DEFAULT_CHAMBER_MIN_KPA =   0.0f;
// Effectively uncapped per-chamber (the unreliable gauge must not gate fills):
// over-pressure is bounded by TIME - the coupled-fill round/sequence caps, the
// manual dead-man, and the actuation watchdog - not by this ceiling. Kept in sync with
// skin_config.MAX_ALLOWED_KPA. (The shared TANK caps above are unchanged.)
constexpr float HARD_CHAMBER_MAX_KPA    =  100.0f;
// Deepest vacuum a chamber may hold - valve-safe, derived from the sensor floor
// (pressure.h): -100 (inert) with the blind 0..100 gauge, -40 with the -40..40
// vacuum sensor so the FA0520E always re-opens. Bounds set_min + the manual cutoff.
constexpr float HARD_CHAMBER_MIN_KPA    = pressure::VACUUM_HOLD_FLOOR_KPA;

struct State {
    bool ready          = false;     // becomes true after autodetect succeeds
    bool error          = false;     // true if autodetect saw <2 PCA9685s
    int  num_chambers   = 0;         // detected count (max 12)

    // Mux channel assignments
    int  chamber_mux_ch[MAX_CHAMBERS] = {};   // mux channel per chamber index
    int  pressure_tank_mux_ch         = -1;
    int  vacuum_tank_mux_ch           = -1;

    // Tank pressure targets and limits.
    // Pressure tank operates in [min, max] with target somewhere inside.
    // Vacuum tank limits are usually negative; same pump-on-when-out-of-range logic.
    float tank_pressure_target_kpa = 0.0f;
    float tank_vacuum_target_kpa   = 0.0f;
    float tank_pressure_max_kpa    = DEFAULT_TANK_PRESSURE_MAX_KPA;
    float tank_pressure_min_kpa    = DEFAULT_TANK_PRESSURE_MIN_KPA;
    float tank_vacuum_max_kpa      = DEFAULT_TANK_VACUUM_MAX_KPA;
    float tank_vacuum_min_kpa      = DEFAULT_TANK_VACUUM_MIN_KPA;
};

inline State state;

}  // namespace config

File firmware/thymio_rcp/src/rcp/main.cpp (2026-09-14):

/*
 * SoftEdIBO - Thymio RCP (XIAO ESP32-C6): dual-transport link + WiFi-OTA.
 *
 * Reads command lines from BOTH the USB-Serial/JTAG port (Serial) and the
 * inter-board UART (Serial1), and replies on the SAME channel - so one binary
 * works flashed-solo-on-USB and wired to the S3 host over TX/RX.
 *
 * Commands (JSON, one per line; the S3 gateway forwards {"target":"thymio",...}
 * here minus "target"):
 *   {"cmd":"ping"}                              -> {"type":"pong","src":"c6"}
 *   {"cmd":"ota_wifi","ssid":..,"pass":..,"url":..}
 *        -> joins the S3's SoftAP, HTTP-pulls the image (its /fw), self-updates
 *           via esp_ota, and reboots into the new firmware. This is why the C6
 *           never needs its USB again once this build is flashed once: all future
 *           updates come over WiFi from the S3. Needs an OTA partition table
 *           (board_build.partitions = default.csv). See docs/THYMIO_WIRELESS_CONTROL.md.
 *   {"cmd":"sniff_start"[,"ch":N]}  -> bring up the 802.15.4 radio in promiscuous
 *           mode and stream every raw frame as {"type":"frame",...} JSON over the
 *           UART (the S3 relays them to the PC). ch omitted -> hop 11..26; else lock.
 *           This is the Phase-1 Thymio-protocol capture (docs/THYMIO_WIRELESS_CONTROL.md)
 *           done on the *boxed* C6: no separate sniffer firmware, so we never lose the
 *           WiFi-OTA path. Never armed at boot -> a radio hiccup is always recoverable
 *           by a reboot (plain RCP again).
 *   {"cmd":"sniff_ch","n":N}        -> lock onto channel N (0 = resume hopping)
 *   {"cmd":"sniff_stop"}            -> radio off, back to a plain RCP
 *   {"cmd":"tx","ch":N,"data":"<hex>"} -> transmit a raw 802.15.4 frame on channel N
 *           (Phase 1: replay/forge a Thymio SET_VARIABLES motor command). Pass the PSDU
 *           WITHOUT its 2-byte FCS - the radio appends it. See the protocol notes below:
 *           motor.left.target=0x56, motor.right.target=0x57, msg type SET_VARIABLES=0xA00C.
 * A bare "PING <n>" line (not JSON) still gets "PONG <n>" for the bring-up link test.
 *
 * Wiring (4 wires): C6 D6/TX(16)->S3 D7/RX(44); C6 D7/RX(17)<-S3 D6/TX(43);
 *   GND-GND; C6 5V<-S3 5V.  Build/flash: pio run -e rcp_c6 -t upload.
 */
#include <Arduino.h>
#include <WiFi.h>
#include <HTTPUpdate.h>
#include <ArduinoJson.h>
#include "esp_ota_ops.h"
#include "esp_ieee802154.h"
#include "freertos/FreeRTOS.h"
#include "freertos/queue.h"
#include "freertos/semphr.h"
#include "freertos/task.h"

static constexpr int      LINK_TX   = 16;      // D6 on the XIAO ESP32-C6
static constexpr int      LINK_RX   = 17;      // D7
static constexpr uint32_t LINK_BAUD = 115200;
static constexpr uint32_t WIFI_TIMEOUT_MS = 15000;
static constexpr int      OTA_ATTEMPTS    = 4;   // retries - the shared-radio AP can
                                                 // drop a sustained bulk download

// Join the S3's SoftAP and pull the staged image from its /fw. httpUpdate reboots
// into the new firmware on success, so this only returns on failure.
static void doWifiOta(const char* ssid, const char* pass, const char* url, Print& io) {
    io.println("{\"type\":\"ota_wifi_start\",\"src\":\"c6\"}");
    WiFi.persistent(false);                     // don't rewrite creds to NVS each begin
    WiFi.mode(WIFI_STA);
    WiFi.setSleep(false);                        // no modem sleep - steadier bulk download
    WiFi.begin(ssid, pass);
    const uint32_t t0 = millis();
    while (WiFi.status() != WL_CONNECTED && millis() - t0 < WIFI_TIMEOUT_MS) delay(200);
    if (WiFi.status() != WL_CONNECTED) {
        io.println("{\"type\":\"ota_wifi_fail\",\"src\":\"c6\",\"reason\":\"wifi\"}");
        WiFi.disconnect(true);
        WiFi.mode(WIFI_OFF);
        return;
    }

    // Retry the pull (OTA_ATTEMPTS): the AP link (shared radio, contended by
    // ESP-NOW) can drop a sustained download. A successful attempt never returns
    // (we reboot into the new image), so the loop only runs on failure - except an
    // ACTIVATE failure, which is not a transport drop and is handled below instead.
    // Download + write + verify via HTTPUpdate, but activate ourselves so we can
    // report the EXACT esp_err (HTTPUpdate only surfaces a generic "err 9").
    httpUpdate.rebootOnUpdate(false);
    WiFiClient client;
    int uerr = 0;
    for (int attempt = 1; attempt <= OTA_ATTEMPTS; ++attempt) {
        t_httpUpdate_return r = httpUpdate.update(client, url);
        if (r == HTTP_UPDATE_OK) {                    // written, verified AND activated
            io.println("{\"type\":\"ota_wifi_ok\",\"src\":\"c6\"}");
            delay(200);
            esp_restart();
        }
        uerr = httpUpdate.getLastError();
        if (uerr == UPDATE_ERROR_ACTIVATE || attempt == OTA_ATTEMPTS) break;
        io.printf("{\"type\":\"ota_wifi_retry\",\"src\":\"c6\",\"attempt\":%d,\"err\":%d}\n",
                  attempt, uerr);
        delay(1000);
    }
    if (uerr == UPDATE_ERROR_ACTIVATE) {
        // Image is written+verified in the inactive slot; only the boot-partition
        // switch failed. Re-do it here to get the real reason + running-slot state.
        const esp_partition_t* run  = esp_ota_get_running_partition();
        const esp_partition_t* next = esp_ota_get_next_update_partition(nullptr);
        esp_ota_img_states_t rst = (esp_ota_img_states_t)0xFF;
        if (run) esp_ota_get_state_partition(run, &rst);
        esp_err_t e = next ? esp_ota_set_boot_partition(next) : ESP_ERR_NOT_FOUND;
        io.printf("{\"type\":\"ota_activate\",\"src\":\"c6\",\"esp_err\":\"%s\","
                  "\"run\":\"%s\",\"run_state\":%d,\"next\":\"%s\"}\n",
                  esp_err_to_name(e), run ? run->label : "?", (int)rst,
                  next ? next->label : "?");
        if (e == ESP_OK) {                            // worked on the retry -> boot it
            io.println("{\"type\":\"ota_wifi_ok\",\"src\":\"c6\"}");
            delay(200);
            esp_restart();
        }
    }
    io.printf("{\"type\":\"ota_wifi_fail\",\"src\":\"c6\",\"reason\":\"http\",\"err\":%d}\n", uerr);
    WiFi.disconnect(true);
    WiFi.mode(WIFI_OFF);
}

// ---- 802.15.4 promiscuous sniffer (Phase 1: capture the Thymio RF protocol) ----
// Frames are streamed as JSON over Serial1 so the S3 relays them to the PC. 127 is
// the full 802.15.4 PSDU, so nothing is ever cut; the worst-case line (~320 chars)
// needs the S3's 384-char relay buffer (gateways on the old 256-char build truncate
// near-max frames - reflash the S3 too). Never armed at boot - a radio hiccup is
// always recoverable by a reboot.
static constexpr uint8_t  SNIFF_MAX_BYTES = 127;
static constexpr uint32_t SNIFF_HOP_MS    = 1500;   // dwell per channel when hopping

struct SniffFrame {
    uint8_t len;
    uint8_t data[128];
    int8_t  rssi;
    uint8_t lqi;
    uint8_t channel;
};
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

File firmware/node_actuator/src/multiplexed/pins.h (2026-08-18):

#pragma once

// ---------------------------------------------------------------------------
// SoftEdIBO node_multiplexed - Pin definitions
//
// Up to 12 chambers, with optional shared positive/vacuum reservoir tanks.
// Sensor reading
// goes through a 74HC4067 16-channel analog mux. Valves are driven by 2x
// PCA9685 I^2C PWM expanders feeding 3x ULN2803A Darlington arrays (24 outputs
// total, labelled UNL1..UNL24 on the schematic). Pumps (6x) go through 3x
// DRV3297 motor drivers.
//
// All pin assignments verified from the schematic netlist.
// ---------------------------------------------------------------------------

// 74HC4067 16-channel sensor mux (U22)
constexpr int SMUX_S0  = 16;   // IO16 -> 74HC4067 pin 10
constexpr int SMUX_S1  = 17;   // IO17 -> pin 11
constexpr int SMUX_S2  = 18;   // IO18 -> pin 14
constexpr int SMUX_S3  = 19;   // IO19 -> pin 13
constexpr int SMUX_SIG = 39;   // SENSOR_VN -> COM (pin 24), ADC1 input-only

// Mux input mapping (verified):
//   I0..I11 -> PSENSOR1..PSENSOR12 (chamber sensors)
//   I12..I15 -> external connectors J47..J50 (intended for tank sensors + spare)

// I^2C bus -> 2x PCA9685 PWM expanders -> 3x ULN2803A -> 24 valve outputs
constexpr int I2C_SDA = 21;
constexpr int I2C_SCL = 22;

// PCA9685 address pins (A0..A5) are FLOATING in the schematic - final
// addresses depend on PCB-level jumpers/solder bridges. Firmware auto-detects
// on boot (I2C scan in 0x40..0x4F range) and uses the two lowest responders
// as PCA #1 (driving UNL1..UNL16 via U6+U8) and PCA #2 (driving UNL17..UNL24
// via U20).

// 3x DRV3297 -> 6 pump PWM inputs (verified)
constexpr int PUMP_PINS[6] = {32, 33, 25, 26, 27, 13};
//                           PUMP1=IO32, PUMP2=IO33, PUMP3=IO25,
//                           PUMP4=IO26, PUMP5=IO27, PUMP6=IO13

constexpr int NUM_PUMPS = 6;

// Maximum chambers supported by the hardware (12 sensor channels x 2 valves).
constexpr int MAX_CHAMBERS = 12;
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

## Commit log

2026-02-24 Exctracted zips to respetive folders
    [KI.kicad_pcb, KI.kicad_sch]
2026-03-02 Fix unacepted MacOS file name in Windows - Rename '3297 EDA - Download de model.textClipping'
2026-03-04 Now only valid USB devices are show in robot panel
2026-03-04 Replaced → with =>
    [main.cpp]
2026-03-07 Fix with flow_layout.py
2026-03-25 Add max pressure configuration for air chambers and enhance logging setup
    - Updated .gitignore to exclude log files.
    - Enhanced README.md with details on per-chamber max pressure settings.
    - Modified air chamber firmware to enforce max pressure limits.
    - Implemented max pressure settings in simulated and real robot controllers.
    - Added centralized logging configuration to improve debugging and error tracking.
    [main.cpp]
2026-03-25 Update README and firmware to reflect changes in air chamber node configuration and pump control
2026-03-25 Enhance status reporting by adding raw ADC values and percentage calculation for each chamber
2026-03-31 kPa instead of % for chamber max pressures
2026-04-28 New system according to the new PCBs
2026-05-01 Add Themio PCB file
2026-05-17 reservoir_node -> multiplexed_node
    [Bigthemio.kicad_pcb, Bigthemio.kicad_sch, Bigthemio.step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]
2026-05-21 3D models
    [Base.stl, Circle Organ.stl, Circle SaraivaSkin.stl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]
2026-05-21 STLs and F3d
    [Base.stl, Circle Organ.stl, Circle SaraivaSkin.stl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]
2026-05-26 Thymio Organ Skin Mold
    [ThymioOrgan.f3d, ThymioOrgan.stl]
2026-06-01 Implementing Sensors from Yaya
2026-06-02 New firmware, ESP32 C6
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2026-06-02 Swapped pins inflate deflate
    [pins.h]
2026-06-03 ESP32 Nodes OTA updates support
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2026-06-08 ci & ota_update fix
    [main.cpp]
2026-06-20 Time based chamber filling
2026-06-22 monitor: chamber/tank/touch-tuning panels as .ui
2026-06-22 add touch-chamber coupling analyzer
2026-06-22 docs: touch coupling, pressure safety, gui arch
2026-06-22 More New 3D Models
    [3Organs.f3d, Organ.stl, OrganAdapter.stl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]
2026-06-23 Adapter for 20mm Skin - Thymio
    [Base.stl, LateralDiagonal.stl, LateralOnX.stl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]
2026-06-24 OTA updates maybe working now, Magnetic sensors merged with node_direct, Gateway as AP too
2026-06-26 3D models 26-06-2026
    [BaseFrame1.stl, FittingTest-0.2.stl, FittingTest-0.4.stl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]
2026-06-27 fixed, chamber not deflating
    [chambers.h]
2026-06-27 late saturday 27-06 fixes
    [main.cpp]
2026-06-28 Trying to fix more thans one chambers inflating at the same time
    [chambers.h, commands.h, leds.h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]
2026-06-28 fixed multi chamber at the same time
    [chambers.h, commands.h, main.cpp]
2026-06-30 Multi chamber inflate/deflate working again!!
2026-07-01 More 3D models...
    [BaseFrame1.stl, FittingTest-0.2.stl, FittingTest-0.4.stl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]
2026-07-03 Working Tyhmio Sound & Sensors via Gateway
2026-07-03 Touch compensation: coupling curves, margin, transition guard, vector mode
2026-07-03 Touch calibration: multi-level staircase sweep + fast telemetry
2026-07-03 Shared se_magnet.h: one magnet module for both boards, runtime stream_vec
2026-07-03 Update platformio.ini to pin exact release tag for pioarduino platform
2026-07-06 Update 3D models
    [BaseFrame1.stl, BaseFrame2.stl, BaseFrame3.stl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]
2026-07-07 Tyhmio Skin Guard and Adapter fix
    [ThymioSkinAdapterwithMagnets.stl, ThymioSkinGuard.stl]
2026-07-07 TreeAdapter Improvement
    [TreeAdapter.stl]
2026-07-07 fix: TreeSkinAdapter LED Ring Inner Diameter
    [TreeSkinAdapter.stl]
2026-07-07 Better touch coupling & thymio without lag
2026-07-08 Gateway Case support for internal antenna
    [GatewayCase.stl, GatewayCaseBottom.stl, GatewayCaseTop.stl]
2026-07-09 Working thymio sensors, and no LAG!!
2026-07-25 Thymio Pipes 3D models
    [ThymioPipeLeft.stl, ThymioPipeRight.stl, ThymioWrinkles.stl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]
2026-07-30 Pcb Tiago
    [Bigthemio.kicad_pcb, Bigthemio.kicad_pcb_bom.csv, Bigthemio.kicad_pcb_positions.csv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]
2026-07-31 move pcb projects to hardware/PCB, drop kicad junk
    [Bigthemio.kicad_pcb, Bigthemio.kicad_pcb_bom.csv, Bigthemio.kicad_pcb_positions.csv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]
2026-08-17 fix bench analysis, vec streaming and update installer edge cases
    [se_magnet.h]
2026-08-18 updated for new thymios and no pressure sensor PCB
2026-08-25 Modelos 3D atualizados e organizados
    [3Organs.f3d, BaseFrame1.stl, BaseFrame2.stl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]
2026-08-25 New tree design
    [OldTreeBase.dxf, TreeAssembly.f3z, TreeBase.dxf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]
2026-08-27 Commom Base 3D Models
    [BaseFrame1.stl, BaseFrame2.stl, BaseFrame3.stl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]
2026-08-29 Turtle 115mm square molds 3D models
    [TurtleNaturalSkin.step, TurtleSquare3Organ.f3d, TurtleSquare3Organ.stl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]
2026-08-31 Commom Base 3D Models fix
    [BoxFrameBackLeft.step, BoxFrameBackLeft.stl, BoxFrameBackRight.step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]
2026-09-02 fix pressure sensor not visible
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2026-09-04 swap sensor idx
2026-09-09 CommomBase lower tolerances
    [BoxFrame.f3z, BoxFrameBackLeft.f3d, BoxFrameBackLeft.stl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]
2026-09-14 Turtle Adpater for Magnet Sensor 3D models
    [TreeTopHoles.dxf, TurtleRectangleTopHoles.dxf, TurtleSquareAdapter.step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]
2026-09-14 pin platformio 6.1.19 in ci
2026-09-17 Some 110mm TurtleSquare Skins
    [TurtleNaturalSkin.stl, TurtleSquareBase.stl, TurtleSquareBaseSiliconeSock.stl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]
2026-09-18 fix mux select clash + fixed sensor map
    [leds.h, main.cpp]
2026-09-18 Turtle Square Skin Holder for Magnets with Inserts
    [TurtleSquareInsertsMagnetsSkinHolder.stl]
2026-09-20 LED Strip on thymio skin 3D and inverted pump polarity 3D
    [ThymioPipeLeft.stl, ThymioPipeRight.stl, ThymioSkinAdapterLEDStrip.stl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]
2026-09-20 multiplexed: 40Hz gauge sweep, window-mean status, manual cut at max_kpa, telemetry while unconfigured, raw adc + pca ids
2026-09-20 direct: raw adc debug frame
2026-09-22 Bug fixes and week improvements
    [SkinTool.stl, ThymioPipeLeft.stl, ThymioPipeRight.stl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]
2026-09-22 soft hold pulses + vacuum hold
    [SkinTool.stl]
2026-09-22 PI hold servo + vacuum hold
2026-09-23 Sheet Cover for Common Base
    [BoxFrameBackLeft.f3d, BoxFrameBackRight.f3d, BoxFrameFrontLeft.f3d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]
2026-09-28 valve column headers in test actuators
2026-09-28 hold keeper + actuators off on test close
2026-10-05 Thymio Lock Mechanism and Buttons for Organ Swap
    [PneumaticConnectorSupportLeft.step, PneumaticConnectorSupportRight.step, SkinTool.stl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]
2026-10-07 push button conditions, button restart activity
2026-10-07 OTA LED variant override, ota_nodes script
2026-10-07 Thymio skin holder without LED ring
    [ThymioSkinHolder.stl, ThymioSkinHolderNoLEDRing.stl]
2026-10-11 OTA LED variant via row dropdown only
2026-10-11 Test Actuators scrolls on small screens
2026-10-11 Refresh ports button label
2026-10-11 binary sensor addresses in skin dialog
2026-10-11 pressure fill default, slot auto-pick, skin tree labels, drop organ editor
2026-10-11 LED tester: send period, preview follows strip layout
2026-10-11 multiplexed: one pump pair per skin, independent engines
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2026-10-12 magnet sample counter and time, two-speed stream, quiet button
2026-10-12 trained model names the gesture, squeeze from chamber pressure rise
2026-10-12 skin dialog: first chamber row not cut off
2026-10-17 multiplexed: fix swapped slots 3/5 and 6/8
2026-10-17 vacuum time replaces min pressure
